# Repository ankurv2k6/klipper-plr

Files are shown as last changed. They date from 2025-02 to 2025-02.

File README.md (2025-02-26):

# Power Loss Recovery Plugin Guide for Klipper

This guide provides a comprehensive overview of the Power Loss Recovery plugin for Klipper 3D printers, explaining its core concepts, workflows, and implementation details. While the example configuration is derived from a Voron 2.4 with four Z steppers, the plugin is designed to work with any printer having up to four Z motors.

## Introduction

The Klipper Power Loss Recovery (PLR) plugin offers automated state saving and recovery functionality for 3D printers running Klipper firmware. In the event of unexpected printer shutdowns, the plugin enables users to resume prints from where they left off, minimizing wasted time and materials.

The plugin's Z+ homing capabilities provide accurate Z-axis calibration after unexpected stoppages, particularly beneficial for printers with multiple Z steppers.

## Demo Video

https://youtu.be/3jmUaCYAoxU

## Installation

### Adding the Plugin to an Existing Klipper Installation

1. **Download the Plugin**
   - Connect to your Klipper host via SSH
   - Navigate to the Klipper extras directory:
   ```bash
   cd ~/klipper/klippy/extras
   ```
   - Download the plugin file:
   ```bash
   wget https://raw.githubusercontent.com/ankurv2k6/klipper-plr/main/power_loss_recovery.py
   ```
   - Ensure proper permissions:
   ```bash
   chmod 644 power_loss_recovery.py
   ```

2. **Restart Klipper**
   - After installing the plugin, restart Klipper to load it:
   ```bash
   sudo service klipper restart
   ```

### Creating a Separate Configuration File

Instead of adding all configuration directly to your main `printer.cfg`, you can create a separate file for the Power Loss Recovery settings:

1. **Create the Configuration File**
   ```bash
   cd ~/printer_data/config
   nano power_loss_recovery.cfg
   ```

2. **Add Configuration to the File**
   ```ini
   # Power Loss Recovery Configuration
   [save_variables]
   filename: ~/printer_data/config/variables.cfg

   [power_loss_recovery]
   debug_mode: False
   save_interval: 30
   save_on_layer: True
   history_size: 3
   save_delay: 2
   
   # Z-PLUS HOMING OPTIONS #
   pin_stepper_z: ^PG10
   pin_stepper_z1: ^PG11
   pin_stepper_z2: ^PG12
   pin_stepper_z3: ^PG13
   
   # Add the rest of your PLR configuration here
   ```

3. **Include the File in Your Main Configuration**
   - Add the following line to your `printer.cfg`:
   ```ini
   [include power_loss_recovery.cfg]
   ```

4. **Add Macros to a Separate File (Optional)**
   - For better organization, you can also keep your PLR macros in a separate file:
   ```bash
   nano power_loss_recovery_macros.cfg
   ```
   - Add the PLR macros to this file
   - Include it in your printer.cfg:
   ```ini
   [include power_loss_recovery_macros.cfg]
   ```

5. **Restart Klipper**
   - After creating and including the config files, restart Klipper:
   ```bash
   sudo service klipper restart
   ```

## Hardware Requirements

### Z-Axis Endstops Configuration

To implement the Z+ homing functionality for printers with multiple Z steppers, you'll need to install endstops appropriate to your printer design:

#### For Floating Gantry Printers (e.g., Voron 2.4)

1. **Endstop Placement**
   - Install microswitches on the corners of the gantry facing upward
   - Install corresponding bumpers on the top of the Z rails/frame
   - The gantry moves up, and the microswitches trigger against the bumpers on the fixed frame

2. **Installation Details**
   - Mount microswitches at each corner of the gantry assembly facing upward
   - Install matching bumpers on the top of the Z rails or top frame at positions that align with each switch
   - Use adjustable mounting solutions to fine-tune the trigger point for each endstop
   - Allow approximately 5-10mm clearance from the physical hard stop

3. **Wiring Considerations**
   - Route wires along the gantry to the moving toolhead cable chain
   - Use shielded cables to reduce electrical noise
   - Secure cables with zip ties or cable management solutions
   - Ensure adequate slack for full Z-axis movement

#### For Floating Bed Printers (e.g., Voron Trident, VzBot)

1. **Endstop Placement**
   - Install endstop switches on the fixed Z columns/rails
   - Install corresponding bumpers on the bed carriage at each Z motor position
   - The bed moves down to trigger the endstops that are mounted on fixed points

2. **Installation Details**
   - Mount microswitches on the Z columns/rails (typically near the top)
   - Attach bumpers to the bed carriage or frame at positions that align with each endstop
   - Ensure proper alignment for consistent triggering
   - Install with adjustable mounting to allow for fine-tuning

3. **Wiring Considerations**
   - Keep wires organized and routed along the fixed frame
   - Ensure wire paths don't interfere with bed or gantry movement
   - Use proper strain relief to prevent cable damage

### Wiring Configuration

Connect each endstop to its designated pin on your control board:
- First Z endstop connects to `pin_stepper_z`
- Second Z endstop connects to `pin_stepper_z1`
- Third Z endstop connects to `pin_stepper_z2`
- Fourth Z endstop connects to `pin_stepper_z3`

### MCU Configuration

- Wire each endstop to an available pin on your MCU
- Configure each pin with pull-up resistors and appropriate debounce

## Single Z Motor Configuration

For printers with a single Z motor controlling a floating bed (like many Cartesian or Bed Slinger printers), the multi-Z stepper homing functionality may not be needed. In these cases:

1. **Comment Out Z-Homing**: For single Z motor printers, you can bypass the Z calibration sequence by modifying the `_PLR_RESUME_PRINT_START` macro in your configuration:

```ini
[gcode_macro _PLR_RESUME_PRINT_START]
gcode:
    {% set resume_info = printer.save_variables.variables.resume_meta_info %}
    _PLR_RESUME_READY      
    # PLR_Z_HOME MODE=RESUME    # Comment out this line for single Z motor printers
    PLR_ENABLE
    G90             ; absolute positioning
    M107            ; turn fan off
    G92 E0                         ; zero the extruder
    G1 E5.0 F1800                  ; extrude filament
    G1 X{resume_info.position.x} Y{resume_info.position.y} Z{resume_info.position.z} F3000
    G92 E0
    G90
    G21
    M83 ; use relative distances for extrusion
    RESTORE_FAN_SPEEDS
```

2. **Standard Homing**: With single Z motor printers, you can use the standard G28 Z for Z-axis homing instead of the PLR's multi-Z calibration system.

3. **Configuration**: You can still use the Power Loss Recovery plugin's state saving and recovery features, just with a simplified Z homing approach:

```ini
[power_loss_recovery]
debug_mode: False
save_interval: 30
save_on_layer: True
history_size: 3
save_delay: 2

# For single Z motor printers, you can omit or comment out the pin_stepper_z1, pin_stepper_z2, etc.
pin_stepper_z: ^z_endstop_pin

# The rest of your PLR configuration
```

This simplified configuration provides the benefits of print recovery without the complexity of multi-Z stepper calibration for printers that don't require it.

## Initial Setup and Calibration

Before using the Power Loss Recovery system for the first time, a proper initial calibration is essential. This establishes the baseline reference that the printer will use when resuming prints.

### Initial Calibration Procedure

1. **Prepare the Printer**
   - Ensure all mechanical components are properly tightened and adjusted
   - Clean all endstop surfaces and Z rails
   - Verify that the bed is properly leveled (if applicable)

2. **Baseline Gantry/Bed Leveling**
   - For floating gantry printers (Voron 2.4):
     - Run a Quad Gantry Level (QGL) procedure: `QUAD_GANTRY_LEVEL`
     - Verify the gantry is square and level to the bed

   - For floating bed printers (Voron Trident, VzBot):
     - Run a Z Tilt Adjust procedure: `Z_TILT_ADJUST`
     - Ensure all Z motors are properly synchronized

3. **PLR Z Calibration**
   - After your standard leveling procedure completes, run the PLR Z homing calibration:
     ```
     PLR_Z_HOME MODE=CALIBRATE
     ```
   - This command will:
     - Home each Z stepper individually against its endstop
     - Measure and store the offsets between Z steppers
     - Calculate a reference position for future recovery operations
     - Save these values to the variables file for persistent storage

4. **Verification**
   - After calibration, check the saved offsets:
     ```
     PLR_QUERY_SAVED_STATE
     ```
   - The command should show offset values for each Z stepper
   - These values represent the height differences between Z steppers

5. **Test Prints**
   - Run a small test print (20-30 minutes)
   - Cancel the print intentionally
   - Use `PLR_RESUME_PRINT` to test the recovery process
   - Check that the first layer after resuming matches the previous layer perfectly

### Calibration Schedule

- Perform a full calibration whenever:
  - You make mechanical changes to the printer
  - You adjust endstop positions
  - Z stepper motors or drivers are replaced
  - After firmware updates that affect motion systems

- For regular maintenance:
  - Recalibrate monthly for high-use printers
  - Recalibrate quarterly for occasional-use printers

## Core Features

### 1. Power Loss Recovery

- **Automated state saving** at configurable intervals
- **Layer change detection** for saving state at critical printing stages
- **Historical state tracking** with configurable delay to ensure mechanical stability
- **Debug logging system** for troubleshooting
- **State verification and validation** for data integrity

### 2. Z+ Homing

- Support for **up to four Z steppers** with individual endstops
- **Fast travel capability** with configurable height and speed
- **Individual stepper probing** with sample collection for accuracy
- **Offset calculation and persistent storage**
- **Error detection and recovery**

## How It Works

### State Saving Workflow

1. **Background Monitoring**: The plugin continuously monitors the printer's state during operation.
2. **State Collection**: At configurable intervals or layer changes, the plugin collects comprehensive state data including:
   - Current position (X, Y, Z coordinates)
   - Current layer and layer height
   - File position and progress
   - Temperature settings (hotend and bed)
   - Fan speeds
   - XYZ offsets

3. **State Validation**: Each collected state is validated for integrity and completeness.
4. **Delayed Storage**: The plugin implements a configurable delay between state collection and storage to account for printer mechanics and ensure a stable state.
5. **Historical Tracking**: Multiple states are maintained in a history queue, allowing for optimal selection based on mechanical conditions.

### Recovery Workflow

1. **File Modification**: When resuming a print, the plugin creates a modified version of the original G-code file, starting from the last saved position.
2. **Z-Axis Calibration**: The plugin performs Z+ homing to ensure proper Z-axis alignment before resumption.
3. **State Restoration**: The plugin restores temperatures, fan speeds, and positional data.
4. **Print Continuation**: The printer resumes printing from the last saved state.

## Configuration Guide

### Basic Setup

Add the following to your `printer.cfg` or to a separate configuration file as described in the installation section:

```ini
[save_variables]
filename: ~/printer_data/config/variables.cfg

[power_loss_recovery]
debug_mode: False                     # Enable detailed logging (default: False)
```

### State Management Options

```ini
#PRINT STATE MANAGEMENT OPTIONS#
save_interval: 30                   # Time between saves in seconds (0-300, default: 30)
save_on_layer: True                 # Whether to save on layer changes (default: True)
history_size: 3                     # Number of states to keep in history (2-20, default: 5)
save_delay: 2                       # States to delay before saving (1-4, default: 2)
```

### Z+ Homing Configuration Example (derived from Voron 2.4)

```ini
# Z-PLUS HOMING OPTIONS #
# Pin configuration (adjust to match your controller board pins)
pin_stepper_z: ^PG10     # First Z stepper endstop pin
pin_stepper_z1: ^PG11    # Second Z stepper endstop pin
pin_stepper_z2: ^PG12    # Third Z stepper endstop pin (if applicable)
pin_stepper_z3: ^PG13    # Fourth Z stepper endstop pin (if applicable)

# Z Stepper Adjustment (tune these values for your specific printer)
stepper_z_adjust_offset: 0.0      # First Z stepper
stepper_z1_adjust_offset: 0.0     # Second Z stepper
stepper_z2_adjust_offset: 0.0     # Third Z stepper (if applicable)
stepper_z3_adjust_offset: 0.0     # Fourth Z stepper (if applicable)

z_height_offset: 0.05       # Additional offset (in mm) to apply to Z height after stepper adjustments

# Probe iteration settings
probe_iteration_count: 1            # Number of times to repeat probing for better accuracy

# Fast Travel Settings
fast_travel_upto_z_height: 250      # Height to fast travel to before homing (adjust for your Z max)
fast_travel_speed: 50               # Speed for fast travel move (mm/s)

# Basic movement settings
z_position: 350.0              # Z position for positive endstop (adjust to your printer's Z height)
fast_move_speed: 5.0           # Speed for initial probing move
slow_homing_speed: 1.0         # Speed for sampling and final homing
max_adjustment: 5.0            # Maximum allowed adjustment distance

# Sampling configuration
sample_size: 3                 # Number of samples to take per stepper
sample_retract_dist: 1.0       # Retraction distance between samples
samples_tolerance: 0.05        # Allowed tolerance between samples
samples_retry_count: 3         # Maximum number of retries for failed probes
samples_tolerance_retries: 3   # Retries allowed for samples outside tolerance
probe_samples_range: 0.07      # Maximum allowed range between highest and lowest samples

retract_dist: 1.0              # Distance to retract after initial probe

# Part Cooling Fan Status
part_cooling_fans: fan
```

### Recovery G-code Options

```ini
#RECOVERY GCODE OPTIONS #
restart_gcode: _PLR_RESUME_PRINT_START   # G-code to add into the modified file to set the printer up correctly to resume printing.

# Pre/Post operation G-code
before_resume_gcode: _PLR_BEFORE_RESUME_GCODE   # G-code to run before resume operations
after_resume_gcode:                # G-code to run after resume operations    
before_calibrate_gcode: G28         # G-code to run before calibration (customize for your printer)
after_calibrate_gcode:             # G-code to run after calibration
```

### Example Macros

These macros handle the recovery sequence:

```ini
[gcode_macro _PLR_RESUME_PRINT_START]
gcode:
    {% set resume_info = printer.save_variables.variables.resume_meta_info %}
    _PLR_RESUME_READY      
    PLR_Z_HOME MODE=RESUME
    PLR_ENABLE
    G90             ; absolute positioning
    M107            ; turn fan off
    G92 E0                         ; zero the extruder
    G1 E5.0 F1800                  ; extrude filament
    G1 X{resume_info.position.x} Y{resume_info.position.y} Z{resume_info.position.z} F3000
    G92 E0
    G90
    G21
    M83 ; use relative distances for extrusion
    RESTORE_FAN_SPEEDS

[gcode_macro _PLR_RESUME_READY]
gcode:
    {% set resume_info = printer.save_variables.variables.resume_meta_info %}
    {% set bed_center_x = printer.configfile.config.stepper_x.position_max|float / 2 %}
    {% set bed_center_y = printer.configfile.config.stepper_y.position_max|float / 2 %}
    
    M140 S{resume_info.bed_temp} # start heating the bed to the temp it was before the failure.
    M109 S{resume_info.hotend_temp} # wait for the toolhead to reach the temp it was printing on before failure
    SET_KINEMATIC_POSITION X={bed_center_x} Y={bed_center_y} Z=0 
    G91
    G1 Z5 F1200 #Clear the print by raising the toolhead
    G90
   
[gcode_macro _PLR_BEFORE_RESUME_GCODE]
gcode:
    {% set bed_center_x = printer.configfile.config.stepper_x.position_max|float / 2 %}
    {% set bed_center_y = printer.configfile.config.stepper_y.position_max|float / 2 %}
    
    G28 X Y      ; Home X and Y
    
    G1 X{bed_center_x} Y{bed_center_y} F2000
    SET_KINEMATIC_POSITION Z=0 

[gcode_macro RESTORE_FAN_SPEEDS]
description: Restore fan speeds from saved state in resume_meta_info
gcode:
    {% set svv = printer.save_variables.variables %}
    {% if 'resume_meta_info' not in svv %}
        { action_respond_info("No saved state found in variables") }
    {% else %}
        {% set state = svv.resume_meta_info %}
        {% if 'fan_speeds' not in state %}
            { action_respond_info("No fan speed data found in saved state") }
        {% else %}
            {% set fan_speeds = state.fan_speeds %}
            {% set cur_extruder = printer.toolhead.extruder %}
            
            # Loop through all saved fan speeds
            {% for fan_name, speed in fan_speeds.items() %}
                {% if fan_name == 'fan' or fan_name == cur_extruder + '_fan' %}
                    # This is a parts cooling fan for current extruder - use M106
                    {% set speed_byte = (speed * 255.0 + 0.5)|int %}
                    M106 P0 S{speed_byte} ; Set parts cooling fan
                    { action_respond_info("Setting parts cooling fan %s using M106: S%d (%.1f%%)" % (fan_name, speed_byte, speed * 100.0)) }
                {% else %}
                    # Check if this is a valid generic fan
                    {% if fan_name in printer %}
                        SET_FAN_SPEED FAN={fan_name} SPEED={speed}
                        { action_respond_info("Setting generic fan %s using SET_FAN_SPEED: %.1f%%" % (fan_name, speed * 100.0)) }
                    {% else %}
                        { action_respond_info("Warning: Fan %s not found - skipping" % fan_name) }
                    {% endif %}
                {% endif %}
            {% endfor %}
        {% endif %}
    {% endif %}
```

## Integration with Existing Macros

### With START_PRINT Macro

Integrate with your standard START_PRINT macro:

```ini
# Add the following to your START_PRINT macro
[gcode_macro START_PRINT]
gcode:
    # Your existing start print commands
    ...
    
    # Add PLR placeholders
    ;;;;; PLR_RESUME - INITIAL PRINTER SETUP STARTS ;;;;;
    # Your normal printer setup code here
    ;;;;; PLR_RESUME - PRINT GCODE STARTS ;;;;;
    
    # Enable PLR for this print
    PLR_ENABLE
    
    # Rest of your start print code
    ...
```

## Usage Guide

### Normal Operation

During normal printing, the Power Loss Recovery plugin automatically saves the printer state based on your configuration settings. No user intervention is required during this process.

### G-code Commands

The plugin provides several G-code commands for manual control:

#### State Management

- `PLR_ENABLE`: Enable power loss recovery state saving
- `PLR_DISABLE`: Disable power loss recovery state saving
- `PLR_SAVE_PRINT_STATE`: Manually save current printer state
- `PLR_QUERY_SAVED_STATE`: Query the current status of the state saver
- `PLR_RESET_PRINT_DATA`: Clear all saved state data

#### Z+ Homing

- `PLR_Z_HOME MODE=CALIBRATE`: Perform Z+ homing and save offsets
- `PLR_Z_HOME MODE=RESUME`: Perform Z+ homing using saved offsets for resume

#### Recovery

- `PLR_RESUME_PRINT`: Create a modified gcode file for power loss recovery resume

#### Bed Mesh Management

- `PLR_SAVE_MESH`: Save the currently active bed mesh profile name
- `PLR_LOAD_MESH`: Load the previously saved bed mesh profile

### Recovering After Unexpected Stoppage

1. After the printer is restarted, run `PLR_QUERY_SAVED_STATE` to confirm saved data
2. Issue `PLR_RESUME_PRINT` to start the recovery process
3. The plugin will:
   - Create a modified G-code file starting from the saved position
   - Perform Z+ homing to ensure proper Z alignment
   - Restore temperatures, fan speeds, and other settings
   - Resume printing from the last saved position

## Best Practices

### Z+ Homing Optimization

For printers with multiple Z steppers:

1. **Initial Calibration**
   - Run `PLR_Z_HOME MODE=CALIBRATE` after ensuring your basic homing is working correctly
   - If your build platform isn't perfectly level after the process, adjust the `stepper_z_adjust_offset` values
   - Typical values range between -0.3 and +0.3 mm

2. **Verification**
   - Run a test print with a large surface area (like a calibration plate)
   - Check first layer consistency across the build platform
   - If any areas show issues, adjust the corresponding Z offset

### Configuration Optimization

1. **Save Interval**: Balance between safety and performance
   - 30-60 seconds works well for most prints
   - For extremely long prints, consider 120 seconds to reduce overhead

2. **History Size and Delay**: Recommendations by printer type
   - For printers with a rigid frame (like Voron), `history_size: 3` and `save_delay: 2` works well
   - For printers with a moving bed (like Prusa style), consider `history_size: 5` and `save_delay: 3`
   - For lightweight direct drive systems, you can reduce `save_delay` to 1

3. **Z+ Homing Settings**: Optimize for your endstop type
   - `sample_size: 3` provides good balance between speed and accuracy
   - `samples_tolerance: 0.05` works well with standard microswitch endstops
   - For inductive probes, increase to `samples_tolerance: 0.075`

### Slicer Integration

For optimal operation, modify your slicer's start and end G-code to include the necessary placeholders:

1. **Start G-code Modification**
   - Add the PLR placeholders after your START_PRINT macro call:
   ```
   ;;;;; PLR_RESUME - INITIAL PRINTER SETUP STARTS ;;;;;
   PLR_DISABLE
   print_start EXTRUDER=[first_layer_temperature[initial_extruder]] BED=[first_layer_bed_temperature]
   PLR_ENABLE
   ;;;;; PLR_RESUME - PRINT GCODE STARTS ;;;;;
   ```

2. **Layer Change G-code**
   - In your slicer's layer change G-code, add:
   ```
   ;LAYER_CHANGE
   ;Z:[layer_z]
   PLR_SAVE_PRINT_STATE_WITH_LAYER LAYER={layer_num} LAYER_HEIGHT={layer_z}
   ```

## Troubleshooting

### Common Issues

1. **Z Homing Problems**
   - **Uneven Homing**: Check mechanical components for each Z stepper
   - **Inconsistent Z Heights**: Verify Z rails or rods are parallel and smooth
   - **Binding During Homing**: Check for debris in Z endstops or mechanical systems

2. **Recovery Misalignment**
   - **X/Y Shift**: Re-check your belts and pulley set screws
   - **Z Layer Shifts**: Possible Z drive system issues, check for mechanical problems
   - **Inconsistent First Layer After Resume**: Adjust Z offsets or run bed leveling before resuming

3. **Endstop Reliability**
   - **False Triggers**: Check for EMI, ensure proper shielding from stepper motors
   - **No Trigger**: Verify endstop wiring and mounting
   - **Inconsistent Triggers**: Clean endstop contact surfaces

### Debug Mode

Enable debug mode for detailed logging:

```ini
[power_loss_recovery]
debug_mode: True
```

Debug logs will be output to both the Klipper log and the printer console.

## Advanced Features

### Optimization Techniques

The plugin implements several optimization techniques:

1. **Adaptive Save Interval**: The plugin can dynamically adjust save intervals based on printing conditions
2. **MCU Load Monitoring**: Checks MCU load before saving state to prevent overloading
3. **Motion Planning Verification**: Ensures mechanical stability before state saving

### Custom Recovery Workflows

You can customize the recovery process for your specific printer by modifying the recovery G-code macros:

```ini
[gcode_macro _PLR_CUSTOM_RESUME]
gcode:
    {% set resume_info = printer.save_variables.variables.resume_meta_info %}
    
    # Printer-specific preparation
    G28                  # Home all axes
    BED_MESH_PROFILE LOAD=default  # Load your default bed mesh
    
    # Heat up with "smart" waiting to reduce oozing
    M104 S{resume_info.hotend_temp}  # Start heating hotend
    M140 S{resume_info.bed_temp}     # Start heating bed
    TEMPERATURE_WAIT SENSOR=heater_bed MINIMUM={resume_info.bed_temp * 0.95}  # Wait for 95% of bed temp
    M109 S{resume_info.hotend_temp}  # Wait for hotend to reach full temp
    
    # Continue with normal resume
    _PLR_RESUME_PRINT_START
```

## Technical Details

### State Data Structure

The saved state contains comprehensive information:

```json
{
  "position": {"x": 150.0, "y": 150.0, "z": 0.2},
  "xyz_offsets": {"x": 0.0, "y": 0.0, "z": 0.1},
  "fan_speeds": {"fan": 0.5},
  "layer": 1,
  "layer_height": 0.2,
  "file_progress": {
    "position": 10000,
    "total_size": 100000,
    "progress_pct": 10.0
  },
  "active_extruder": "extruder",
  "hotend_temp": 240.0,
  "bed_temp": 110.0,
  "current_file": "benchy.gcode"
}
```

### Z+ Homing Process

The Z+ homing process for multiple Z steppers follows these steps:

1. **Initial Probe**: First Z stepper (stepper_z) is used as reference
2. **Individual Probing**: Each Z stepper is probed independently
3. **Offset Calculation**: Offsets are calculated relative to the reference stepper
4. **Offset Application**: Offsets are applied to ensure a level build platform
5. **Final Home**: A final homing move ensures calibration accuracy

## Conclusion

The Klipper Power Loss Recovery plugin, when properly configured for your specific printer, provides a robust solution for recovering from unexpected print interruptions. The plugin's Z+ homing capabilities are particularly valuable for printers with multiple Z steppers, ensuring a perfectly level build platform upon recovery.

By integrating this plugin with your printer's existing macros and carefully tuning the Z stepper offsets, you can significantly improve the reliability and usability of your 3D printer.

For further assistance, refer to the full source code documentation or submit issues through the repository's issue tracker.

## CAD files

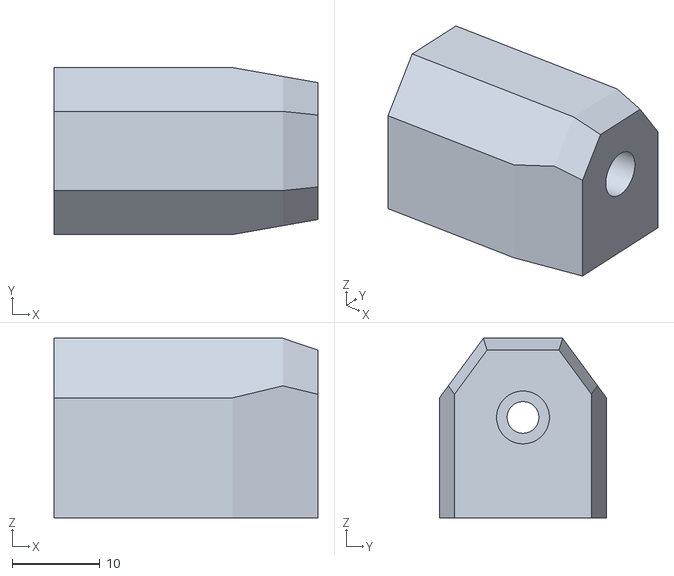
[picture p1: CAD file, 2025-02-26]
STL/Voron 2.4/voron_24_rail_top_bumper.stl
30.0 x 19.0 x 20.4

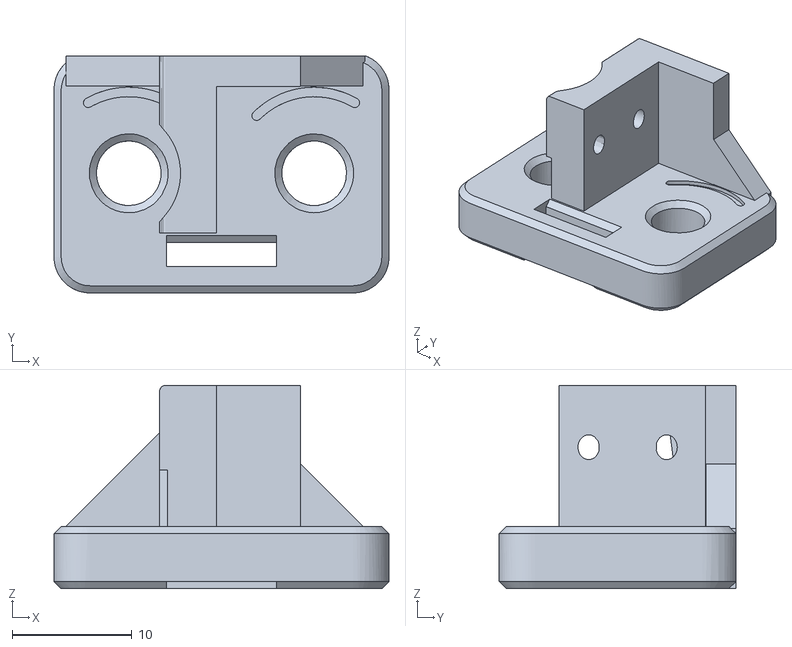
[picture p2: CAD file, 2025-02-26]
STL/Voron 2.4/voron_24_belt_clip_a.stl
28.0 x 19.8 x 17.0

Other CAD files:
STL/Voron 2.4/voron_24_belt_clip_b.stl

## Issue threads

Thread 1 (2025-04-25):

Z+ Homing using Sensorless homing

Quintine, 2025-04-25:
I know this is not really something that is supported however was messing around.

I can get z0 to happily register
However z1,z2,z3 will drift their positions and not seem to move back up after getting a home position.

I have klipper logs if needed.
Switches are on their way in the mail currently.

giutritto, 2025-05-27:
hi,

I'm facing a problem whit my custom printer (SKR-3, Klipper, double z stepper, with Bltouch probe). I receive errors with "PLR_Z_HOME MODE=CALIBRATE" command.
First Error was: Z calibration failed: Error probing stepper_z: BLTouch failed to deploy
After some changes last error is: Z calibration failed: No trigger on probe after full movement

here the debug log:

09:50 Z calibration failed: No trigger on probe after full movement
09:50 PLR LOG:: Error in Z calibration: No trigger on probe after full movement
09:49 PLR LOG:: Fast travel to Z=60.000 at 50.0 mm/s
09:49 PLR LOG:: Initial position: X112.000 Y112.000 Z5.000
09:49 PLR LOG:: Performing initial probe with first endstop
09:49 PLR LOG:: Speed: 50.0 mm/s
09:49 PLR LOG:: Height: 60.0 mm
09:49 PLR LOG:: Fast travel parameters:
09:49 PLR LOG:: Initial speed: 1.0 mm/s
09:49 PLR LOG:: Z endstop position: 60.0
09:49 PLR LOG:: Movement parameters:
09:49 PLR LOG:: Starting PLR Z Home in CALIBRATE mode
09:49 PLR_Z_HOME MODE=CALIBRATE
09:49 G28

any help will be appreciate

[config-20250527-101519.zip](https://github.com/user-attachments/files/20453062/config-20250527-101519.zip)
